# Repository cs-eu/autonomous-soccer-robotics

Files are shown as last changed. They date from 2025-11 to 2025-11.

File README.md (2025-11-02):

# Autonomous Soccer Robot

An autonomous, competition-ready soccer robot designed and built for a educational robotics competition.

---

## Overview

The **Autonomous Soccer Robot** was engineered to:

* Detect and track a ball using 360° vision
* Navigate the field holonomically in any direction
* Handle and shoot the ball autonomously
* Operate completely untethered under RoboCupJunior Soccer rules

Every part — from the **mechanical design** and **custom PCBs** to the **embedded firmware** and **computer vision** algorithms — was developed by our team.

This repository provides a complete, open-source reference for educational and research use.

---

## Project Structure

```
.
├── docs/                # Documentation and reference material
│   ├── electronics/     # Schematics, PCB layouts, and Eagle files
│   ├── hardware/        # CAD designs, drawings, and mechanical notes
│   └── parts-lists/     # Component, ordering, and assembly lists
│
├── firmware/            # Embedded control software (C/C++ / PlatformIO)
│   ├── calibration-tools/  # Sensor calibration and testing utilities
│   ├── main-controller/    # High-level control (movement, PID, logic)
│   ├── sensor-node/        # Sensor acquisition and preprocessing
│   └── tests/              # Unit and integration tests
│
├── libraries/           # Shared hardware abstraction and logic libraries
│   ├── Bodensensoren/   # Floor sensor modules
│   ├── IMU/             # IMU driver and orientation estimation
│   ├── TOF/             # Time-of-Flight distance sensing
│   ├── Motors/          # Motor control and PID regulation
│   ├── TACTICS/         # Robot state machine and strategy modules
│   └── ...              # Additional hardware interface libraries
│
├── mechanical/          # Physical design and fabrication files
│   ├── 3d-models/       # Fusion 360 models and 3D-print files (.stl, .f3d)
│   ├── eagle-pcb/       # Custom PCB layouts and Eagle libraries
│   └── metal-fabrication/ # CNC drawings, step files, and laser-cut designs
│
└── vision/              # Computer vision and image processing
    ├── docker/          # Dockerfiles for OpenCV build environments
    └── tinkerboard/     # Tinker Board vision software (Python + OpenCV)
```

---

## System Architecture

### Hardware Overview

* **Drive System:** Three-wheel omnidirectional base (holonomic drive)
* **Dribbler:** DC-motor-driven adhesive roller for ball handling
* **Kicker:** Solenoid-based shooting mechanism powered via capacitor buffer
* **Main Controller:** Dual **Teensy 3.6** microcontrollers for control & sensing
* **Vision Processor:** **ASUS Tinker Board** running OpenCV (Python)
* **Sensors:**

  * Raspberry Pi camera + parabolic mirror (360° vision)
  * 4× Time-of-Flight (ToF) distance sensors
  * 32× photoresistor array with RGB illumination for boundary detection

---

## Software Overview

| Layer | Platform | Language | Description |
| --- | --- | --- | --- |
| **Vision** | Tinker Board (SBC) | Python + OpenCV | Detects the ball and extracts angular bearing |
| **Control** | Teensy 3.6 | C/C++ (Arduino Framework) | Motion control, PID regulation, actuator management |
| **Communication** | Serial protocol (custom CRC) | C/Python | Reliable low-latency data exchange (<20 ms loop time) |

### Control Loop

The control system computes translational and rotational velocities from sensor inputs, applying:
[
u(t) = K_p e(t) + K_i \int e(t),dt + K_d \frac{de(t)}{dt}
]
Each wheel’s speed is regulated through independent PID loops for smooth, responsive motion.

---

## Mechanical Design

The chassis combines **CNC-milled aluminum** for structural integrity with **3D-printed polymer shells** for lightweight coverage and modular maintenance.
All components were modeled in **Autodesk Fusion 360**, allowing precise alignment and rapid iteration.

---

## Electronics

* **Custom PCBs** for motor drivers, solenoid control, and power regulation
* Designed using **Autodesk Eagle**
* Multiple voltage rails (12V / 5V / 3.3V) with overcurrent and thermal protection
* Modular connectors for fast servicing during competition

---

## Vision and Perception

The 360° vision system uses a **catadioptric setup** (camera + parabolic mirror) to obtain a full panoramic field view.
Processing steps include:

1. Image unwarping to cylindrical projection
2. Color filtering to detect the orange ball
3. Contour and centroid extraction
4. Angular position estimation relative to robot center

Additional data from ToF sensors and photoresistors provide:

* Boundary line detection
* Obstacle proximity sensing
* Position estimation support

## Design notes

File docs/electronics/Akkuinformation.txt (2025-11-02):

Minute  0: 12,6 V
Minute 10: 11,7 V

6x zusätzliches Startup-Warten (Pi zieht 3 A)

danach 725 mAh reingeladen

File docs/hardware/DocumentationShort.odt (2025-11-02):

OborRobotics – Robocup Junior Soccer

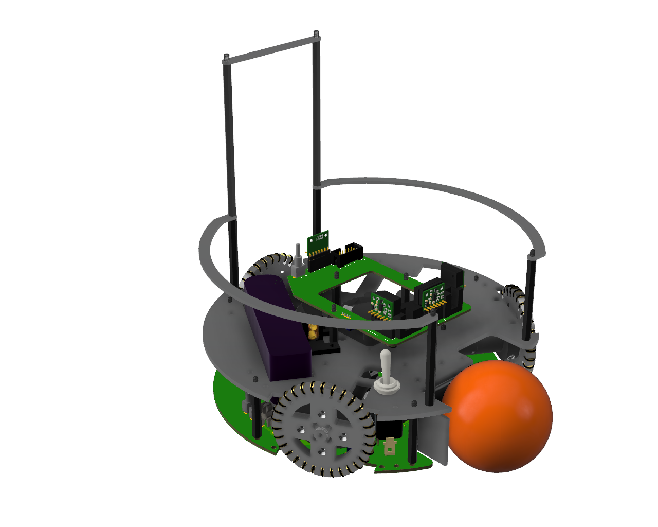
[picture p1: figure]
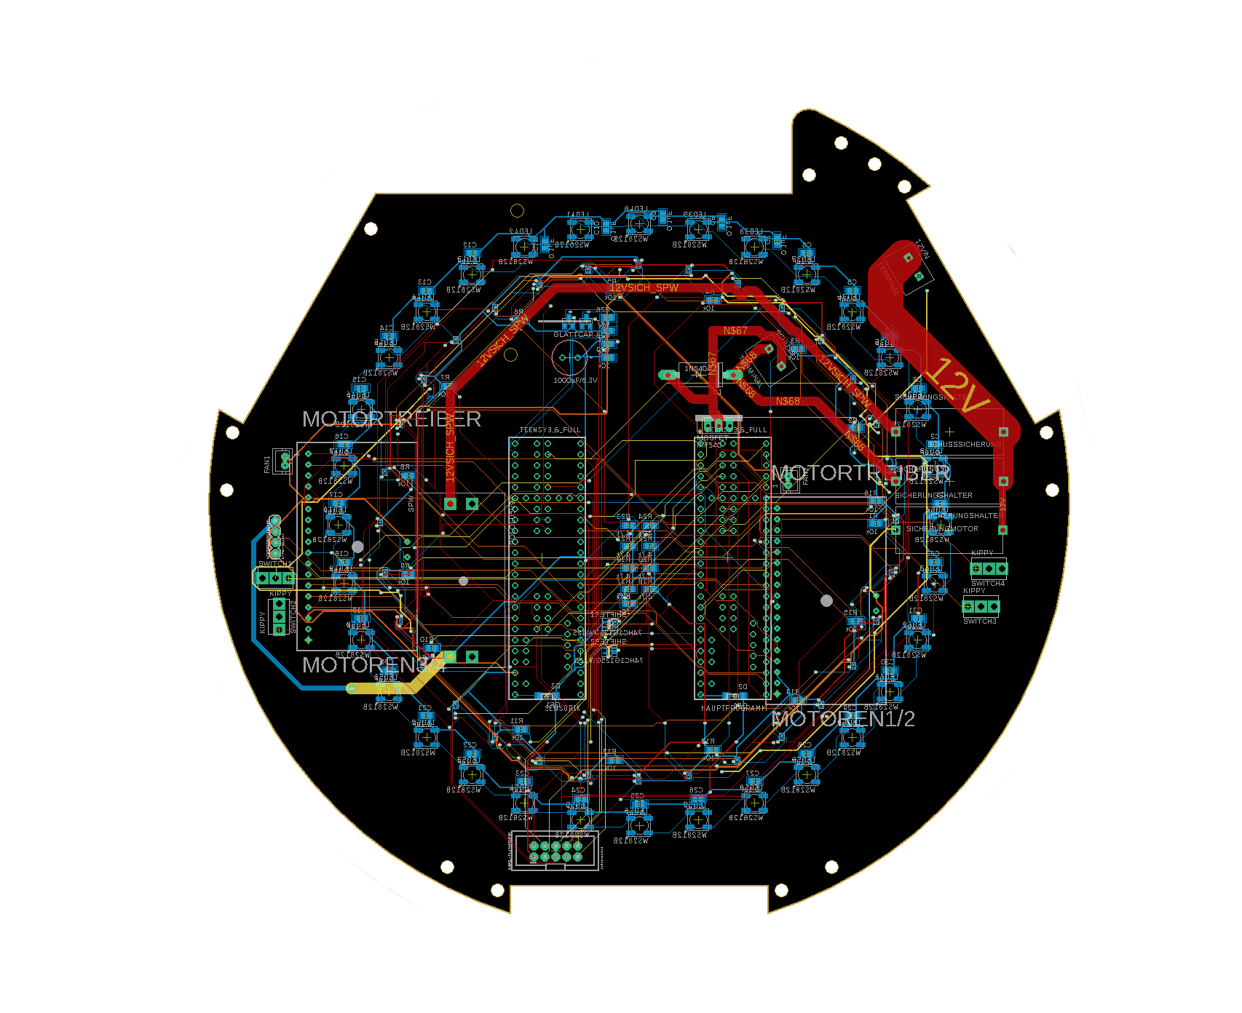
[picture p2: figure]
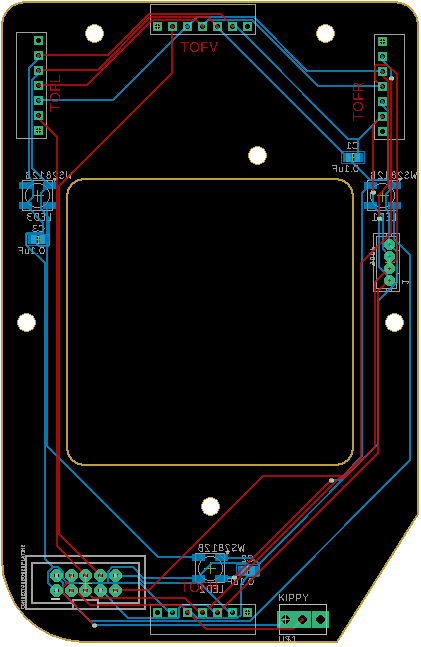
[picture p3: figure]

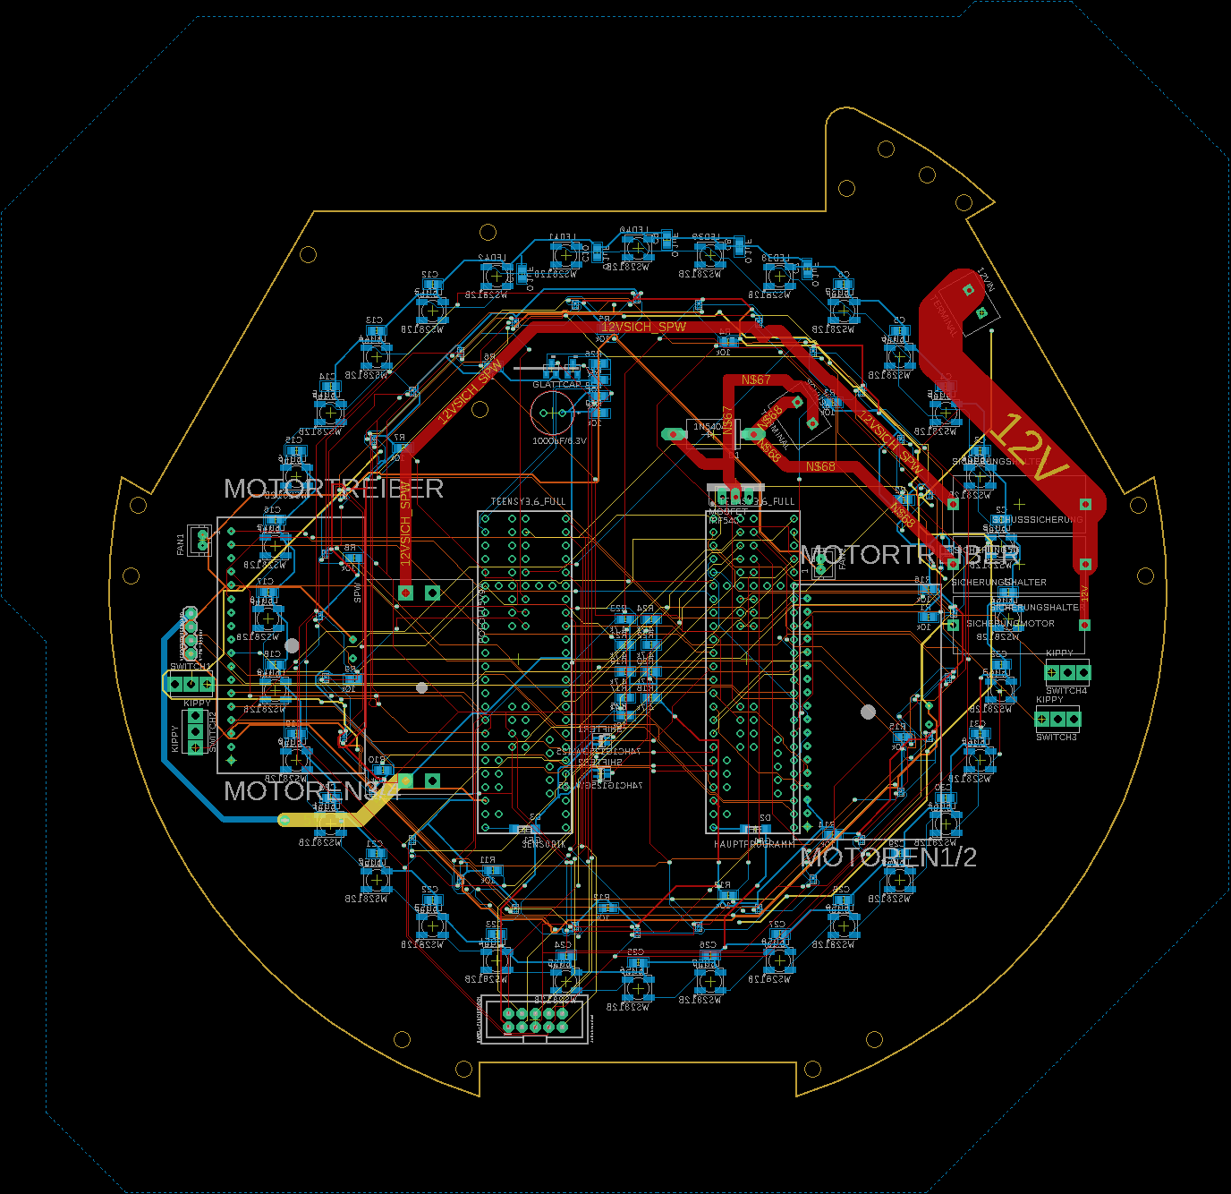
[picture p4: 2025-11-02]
mechanical/3d-models/renders/Pcb1V1.png

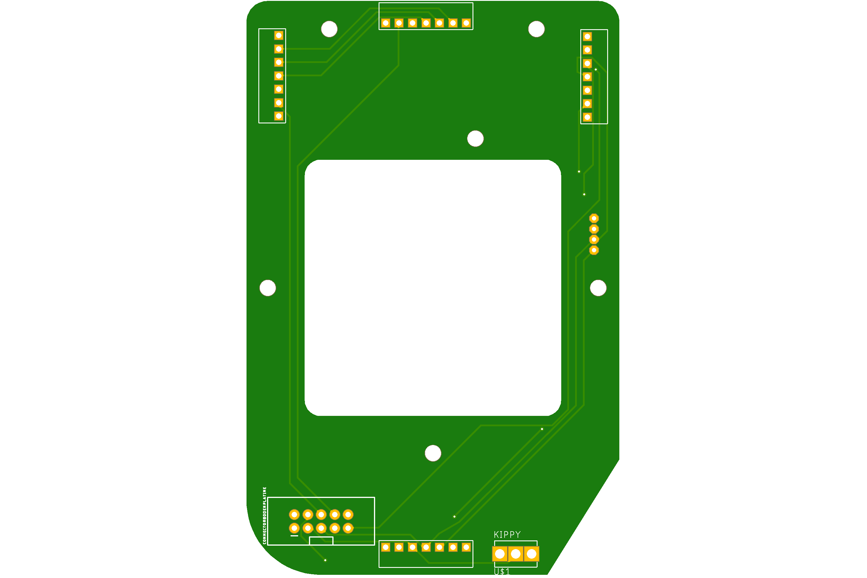
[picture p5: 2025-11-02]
docs/electronics/PlatineObenBoardTop.png

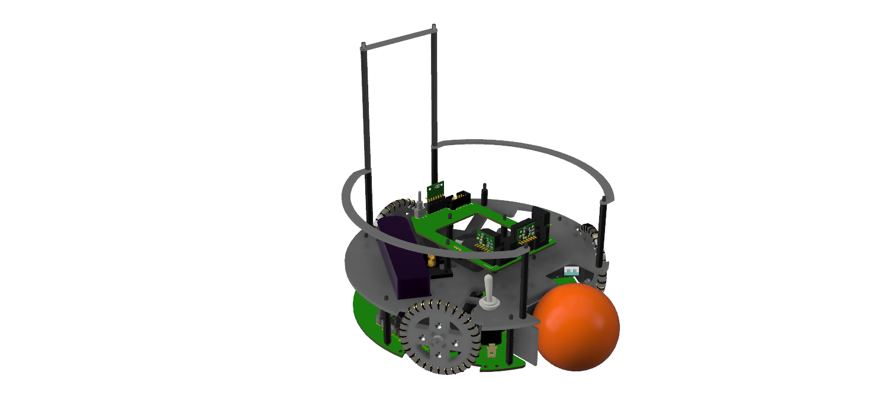
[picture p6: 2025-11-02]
mechanical/3d-models/renders/RenderingRoboV2.png

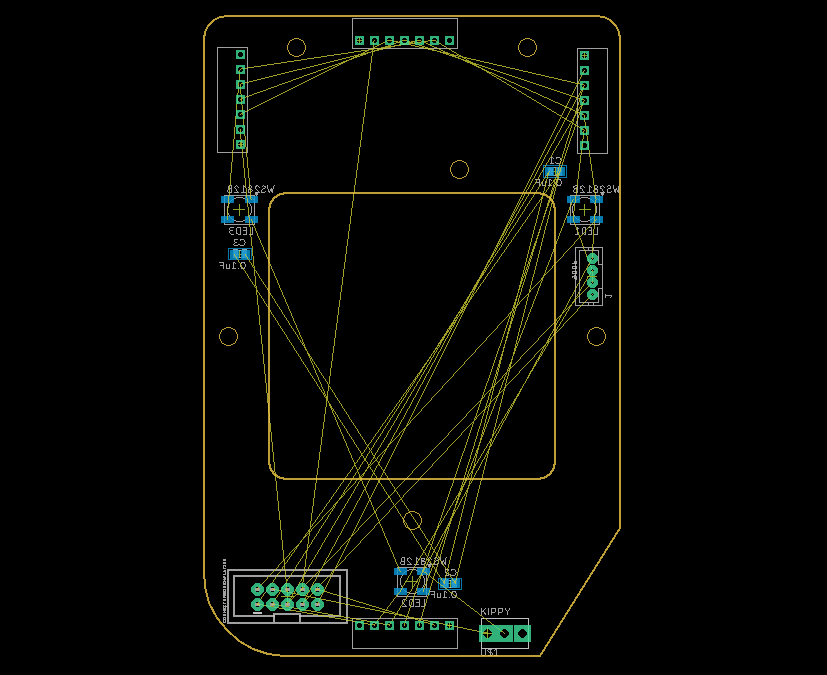
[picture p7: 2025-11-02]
mechanical/3d-models/renders/Pcb2V2.png

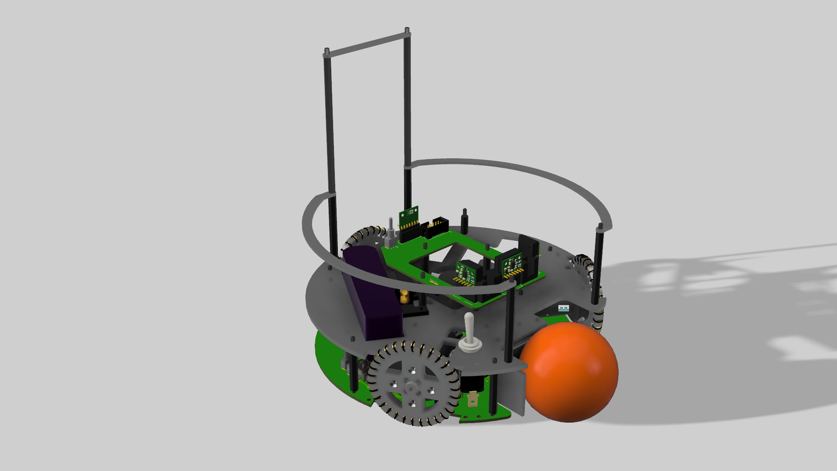
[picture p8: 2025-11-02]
mechanical/3d-models/renders/RenderingRoboV3.png

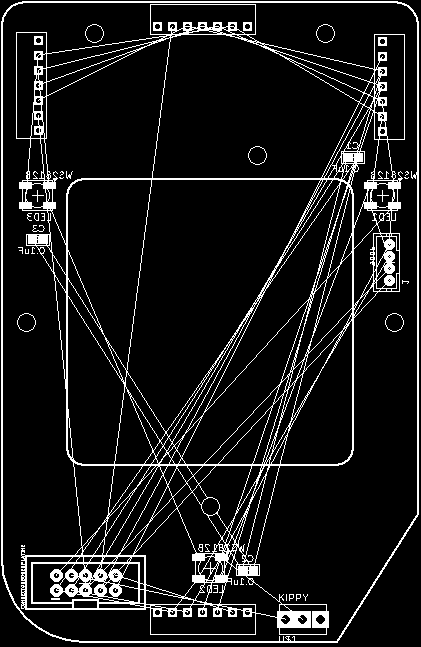
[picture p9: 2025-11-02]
mechanical/3d-models/renders/Pcb2V3.png

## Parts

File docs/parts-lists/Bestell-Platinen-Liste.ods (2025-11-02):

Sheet: Bestellungen_3D-Modelle
 | 3D-Modell benötigt | Step vorhanden?
MotortreiberPins | MotortreiberPlatzhalter | ja
MotortreiberPins | MotortreiberPlatzhalter | ja
Arduino | Anschlussleiste ja, Arduino einzeln | ja
Kompass (Pins)
AkkuPins
UltraschallPins
Fotowiderstände | ja | ja
LEDs | ja | ja
Schalter | ja | ja
StromkreisSchalter | ja | ja
ZustandLEDs | ja | ja
LichtschrankenUltraschall (eventuell)
MotortreiberTermials | ja | ja | https://www.reichelt.de/loetbare-schraubklemme-2-pol-rm-5-mm-90-rnd-205-00012-p170244.html?trstct=pol_0
Pi Zero | ja | ja
Spannungswandler (DEBO DCDC 20W) | ja | ja
Kabel | Platzhalter
Bestellung2:
PiZero x 1
PiCam (RPI JT CAM 5MP) x2
RND 205-00012 :: Lötbare Schraubklemme - 2-pol, RM 5 mm, 90° | reichelt 4x
10x Schalter (https://www.conrad.de/de/kippschalter-125-vac-1-x-einein-tru-components-tc-mk244z-rastend-1-st-1589425.html)
10*Sicherung 1,4 A | https://www.reichelt.de/feinsicherung-5x20mm-mitteltraege-1-4a-mtr-1-4a-p13240.html?&trstct=pol_1
10*Sicherung 10 A | https://www.reichelt.de/feinsicherung-5x20mm-flink-10a-flink-10a-p26479.html?&trstct=pol_0
10*Sicherung 3,15A | https://www.reichelt.de/feinsicherung-5x20mm-flink-3-15a-flink-3-15a-p7836.html?&trstct=pol_0
10*Sicherungshalter 5*20mm | https://www.reichelt.de/sicherungshalter-5x20mm-max-10a-250v-pl-ogn-25-p35196.html?&trstct=pol_4
4*Schuss-Mosfet | https://www.reichelt.de/mosfet-p-ch-100v-23a-140w-to-220ab-irf-9540n-p41638.html?r=1
4*Flyback-Diode | https://www.reichelt.de/gleichrichterdiode-400-v-3-a-do-201ad-1n-5404-p1749.html?r=1
4*Stromkreis-Schalter | https://www.conrad.de/de/sci-kfz-kippschalter-r13-423l-green-12-vdc-30-a-1-x-ausein-rastend-1-st-701050.html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
Kabel + pin header
Schalter:
1x Strom an/aus
1x Programm an/aus
1x Schusstest

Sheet: Pinout
Arduino | Funktion | Eagle? | ZUSATZ | Arduino Nano | Funktion | ZUSATZ
0 |  |  |  | 0 | RX | Arduino Mega
1 |  |  |  | 1 | TX | Arduino Mega
2 | U1E | x |  | 2 | SPI CLOCK
3 | U2E | x |  | 3 | SPI MOSI
4 | U2T | x |  | 4 | SPI MISO
5 | U1T | x |  | 5 | BODEN1
6 | U3T | x |  | 6 | BODEN2
7 | SCHUSS MOSFET | x |  | 7 | BODEN3
8 | U4T | x |  | 8 | BODEN4
9 |  |  |  | 9 | BODEN5
10 | SWITCH1 | x |  | 10 | BODEN6
11 | SWITCH2 | x |  | 11 | BODEN7
12 | SWITCH3 | x |  | 12 | BODEN8
13 | SWITCH4 | x |  | 13
14 | TX |  | RPI | 14
15 | RX |  | RPI | 15
16 | TX | x | Nano (TX Mega) | 16
17 | RX | x | Nano (RX Mega) | 17
18 | U3E | x |  | 18
19 | U4E | x |  | 19
20 | SDA | x | KOMPASS | 20
21 | SCL | x | KOMPASS
22
23
24
25
26
27
28 | M1FB | x | Motor 1 Feedback
29 | M1SF | x | Motor 1 Security
30 | M2FB | x | Motor 2 Feedback
31 | M2SF | x | Motor 2 Security
32 | M3FB | x | Motor 3 Feedback
33 | M3SF | x | Motor 3 Security
34 | M4FB | x | Motor 4 Feedback
35 | M4SF | x | Motor 4 Security
36 | M1D1 | x | Motor 1 Dir 1
37 | M1D2 | x | Motor 1 Dir 2
38 | M2D1 | x | Motor 2 Dir 1
39 | M2D2 | x | Motor 2 Dir 2
40 | M3D1 | x | Motor 3 Dir 1
41 | M3D2 | x | Motor 3 Dir 2
42 | M4D1 | x | Dribbler Dir 1
43 | M4D2 | x | Dribbler Dir 2
44 | M1S | x | PWM
45 | M2S | x | PWM
46 | M3S | x | PWM
47 | M4S | x | NICHT PWM !!!!!! DRIBBLER
48
abxy
14

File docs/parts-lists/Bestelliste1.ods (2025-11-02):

Bezeichnung | Stückzahl | Einzelpreis | Gesamtpreis | Webshop | Artikelnummer | Status | Link
Kugellager Mr105ZZ | 6 | 2,49 € | 14,94 € | Conrad | 295620 – NA | nicht bestellt | https://www.conrad.de/de/p/reely-bb051004-rc-car-kugellager-chromstahl-innen-durchmesser-5-mm-aussen-durchmesser-10-mm-drehzahl-max-50000-u-mi-295620.html
Riemenscheibe Bohrung 3mm | 3 | 3,49 € | 10,47 € | Mechatronics-Pro | 685293887530 | nicht bestellt | https://www.mechatronics-pro.de/de/riemenscheibe-kurz-gt2-6mm-16-zaehne-bohrung-3mm_480.html
Riemenscheibe Bohrung 5mm | 3 | 3,69 € | 11,07 € | Mechatronics-Pro | 685293821480 | nicht bestellt | https://www.mechatronics-pro.de/de/riemenscheibe-kurz-gt2-6mm-20-zaehne-bohrung-5mm_397.html
Lüfter 30x30 | 3 | 10,99 € | 32,97 € | Conrad | 1664489 – NA | nicht bestellt | https://www.conrad.de/de/p/sepa-mfb30e12-axialluefter-12-v-dc-4-0-m-h-l-x-b-x-h-30-x-30-x-6-5-mm-1664489.html
Zahnriemen 96mm | 4 | 2,89 € | 11,56 € | Gtech-Shop | C2-05.05 | nicht bestellt | https://www.gtech-shop.de/GT2-Zahnriemen-6-mm-96-mm-48-Zaehne
Stahlwelle 5mm | 1 | 3,09 € | 3,09 € | Conrad | 237078 - NA | nicht bestellt | https://www.conrad.de/de/p/silberstahl-welle-reely-x-l-5-mm-x-500-mm-237078.html
M4 Sicherungsmutter | 1 | 2,09 € | 2,09 € | Conrad | 223409 - NA | nicht bestellt | https://www.conrad.de/de/p/toolcraft-223409-sicherungsmuttern-m4-din-985-stahl-verzinkt-10-st-223409.html
M4x16 Edelstahl | 10 | 0,14 € | 1,40 € | Conrad | 888747 – NA | nicht bestellt | https://www.conrad.de/de/p/toolcraft-888747-zylinderschrauben-m4-16-mm-innensechskant-din-912-edelstahl-a2-1-st-888747.html
M4 Muttern | 1 | 1,19 € | 1,19 € | Conrad | 888119 – NA | nicht bestellt | https://www.conrad.de/de/p/toolcraft-888119-sechskantmuttern-m4-din-934-edelstahl-a2-10-st-888119.html
M3x10 Edelstahl | 25 | 0,07 € | 1,75 € | Conrad | 888738 – NA | nicht bestellt | https://www.conrad.de/de/p/toolcraft-888738-zylinderschrauben-m3-10-mm-innensechskant-din-912-edelstahl-a2-1-st-888738.html
M3x12 Edelstahl | 30 | 0,08 € | 2,40 € | Conrad | 888739 – NA | nicht bestellt | https://www.conrad.de/de/p/toolcraft-888739-zylinderschrauben-m3-12-mm-innensechskant-din-912-edelstahl-a2-1-st-888739.html
M4x12 Senkkopf | 10 | 0,10 € | 1,00 € | Conrad | 889768 – NA | nicht bestellt | https://www.conrad.de/de/p/toolcraft-889768-senkschrauben-m4-12-mm-kreuzschlitz-phillips-din-965-stahl-verzinkt-1-st-889768.html
M4x4 Gewindestift | 1 | 1,49 € | 1,49 € | Conrad | 1789865 – NA | nicht bestellt | https://www.conrad.de/de/p/toolcraft-to-5369595-gewindestift-m4-4-mm-edelstahl-a1-a2-50-st-1789865.html
M3x10 Senkkopf | 1 | 3,49 € | 3,49 € | Conrad | 1791990 – NA | nicht bestellt | https://www.conrad.de/de/p/toolcraft-to-5375970-senkschrauben-m3-10-mm-kreuzschlitz-phillips-iso-7046-edelstahl-a2-200-st-1791990.html
M2x8 Edelstahl | 15 | 0,31 € | 4,65 € | Conrad | 888725 – NA | nicht bestellt | https://www.conrad.de/de/p/toolcraft-888725-zylinderschrauben-m2-8-mm-innensechskant-din-912-edelstahl-a2-1-st-888725.html
M2x6 Senkkopf | 10 | 0,08 € | 0,80 € | Conrad | 889751 – NA | nicht bestellt | https://www.conrad.de/de/p/toolcraft-889751-senkschrauben-m2-6-mm-kreuzschlitz-phillips-din-965-stahl-verzinkt-1-st-889751.html
M2.5x16 Senkkopf | 1 | 3,99 € | 3,99 € | Conrad | 1810566 – NA | nicht bestellt | https://www.conrad.de/de/p/toolcraft-to-5431698-senkschrauben-m2-5-16-mm-kreuzschlitz-phillips-iso-7046-stahl-galvanisch-verzinkt-200-st-1810566.html
M2.5 Muttern | 1 | 1,29 € | 1,29 € | Conrad | 106856 – NA | nicht bestellt | https://www.conrad.de/de/p/toolcraft-106856-sechskantmuttern-m2-5-din-439-stahl-100-st-106856.html
Encoder | 9 | 14,74 € | 132,66 € | Mouser | 985-AS5601-SO_EK_A | nicht bestellt | https://www.mouser.de/ProductDetail/ams/AS5601-SO_EK_AB?qs=pqSajtDZXRWFkB8SVj5xrw%3D%3D
Abstandsbolzen 40mm M3 | 1 | 3,49 € | 3,49 € | Conrad | 521716 – NA | nicht bestellt | https://www.conrad.de/de/p/pb-fastener-s45530x40-abstandsbolzen-l-40-mm-m3-x-7-m3-x-6-stahl-verzinkt-10-st-521716.html
M3x12 Senkkopf | 25 | 0,07 € | 1,75 € | Conrad | 889762 – NA | nicht bestellt | https://www.conrad.de/de/p/toolcraft-889762-senkschrauben-m3-12-mm-kreuzschlitz-phillips-din-965-stahl-verzinkt-1-st-889762.html
Abstandsbolzen 20mm M3 | 20 | 0,30 € | 6,00 € | Conrad | 526657 – 62 | nicht bestellt | https://www.conrad.de/de/p/6035-20-m3-abstandsbolzen-l-20-mm-m3-m3-messing-1-st-526657.html
M3x8 Edelstahl | 25 | 0,09 € | 2,25 € | Conrad | 888736 – 62 | nicht bestellt | https://www.conrad.de/de/p/toolcraft-888736-zylinderschrauben-m3-8-mm-innensechskant-din-912-edelstahl-a2-1-st-888736.html
M3 Muttern | 1 | 0,82 € | 0,82 € | Conrad | 131880 – 62 | nicht bestellt | https://www.conrad.de/de/p/toolcraft-131880-sechskantmuttern-m3-din-934-stahl-100-st-131880.html
M3x20 Senkkopf | 10 | 0,08 € | 0,80 € | Conrad | 889764 – 62 | nicht bestellt | https://www.conrad.de/de/p/toolcraft-889764-senkschrauben-m3-20-mm-kreuzschlitz-phillips-din-965-stahl-verzinkt-1-st-889764.html
Platine: |  |  |  |  |  | nicht bestellt
Teensy 4.0 | 3 | 29,50 € | 88,50 € | Reichelt | TEENSY 4.0 | nicht bestellt | https://www.reichelt.de/teensy-4-0-usb-teensy-4-0-p269006.html?&trstct=pos_0&nbc=1
Stiftleiste 1*14 | 6 | 0,69 € | 4,14 € | Reichelt | BKL 10120917 | nicht bestellt | https://www.reichelt.de/stiftleiste-2-54mm-1x14-h-11-6mm-gerade-bkl-10120917-p262781.html?trstct=pol_25&nbc=1
Buchsenleiste 1*14 | 6 |  | 0,00 € |  |  | nicht bestellt
Stiftleiste 2*5 | 3 |  | 0,00 € |  |  | nicht bestellt
Buchsenleiste 2*5 | 3 |  | 0,00 € |  |  | nicht bestellt
Stiftleiste 1*5 | 3 | 0,29 € | 0,87 € | Reichelt | BKL 10120502 | nicht bestellt | https://www.reichelt.de/stiftleiste-5-polig-vergoldet-2-54mm-bkl-10120502-p235653.html?trstct=pol_4&nbc=1
Buchsenleiste 1*5 | 3 |  | 0,00 € |  |  | nicht bestellt
Teensy 3.6 | 0 | 0,00 € | 0,00 € |  |  | nicht bestellt
Buchsenleiste 1*24 | 6 |  | 0,00 € |  |  | nicht bestellt
Buchsenleiste 2*3 | 3 |  | 0,00 € |  |  | nicht bestellt
Buchsenleiste 2*4 | 3 |  | 0,00 € |  |  | nicht bestellt
Buchsenleiste 2*5 | 3 |  | 0,00 € |  |  | nicht bestellt
Led WS2812B | 96 |  | 0,00 € |  |  | nicht bestellt
Levelshifter | 6 |  | 0,00 € |  |  | nicht bestellt
Kondensatoren 1u.F | 96 |  | 0,00 € |  |  | nicht bestellt
I2C Multiplexer TCA9548APWR | 12 | 1,15 € | 13,80 € | Mouser | 595-TCA9548APWR | nicht bestellt | https://www.mouser.de/ProductDetail/Texas-Instruments/TCA9548APWR?qs=sGAEpiMZZMsKdvST4JBTTEPriY5kCzuu
Widerstand 4.7kO | 216 |  | 0,00 € |  |  | nicht bestellt
Widerstand 10kO | 12 |  | 0,00 € |  |  | nicht bestellt
BodensensorenTSL2584TSV | 96 |  | 0,00 € |  |  | nicht bestellt
Motorcontroller DRV8320HRTV | 12 | 2,59 € | 31,08 € | Mouser |  | nicht bestellt
Mosfets TPH9R506PL | 72 | 0,66 € | 47,30 € | Mouser | 757-TPH9R506PLLQ | nicht bestellt | https://www.mouser.de/ProductDetail/Toshiba/TPH9R506PLLQ
Motorconnector TE1-84953-1 | 12 | 0,94 € | 11,28 € | Mouser | 571-1-84953-1 | nicht bestellt | https://www.mouser.de/ProductDetail/TE-Connectivity/1-84953-1/?qs=uUkeXfjQ8uQbyHjuXR99Yw%3D%3D

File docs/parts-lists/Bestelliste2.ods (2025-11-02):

Bauteil | Kosten | Anzahl | Webshop | Artikelnummer | Status | Link
PiCam (RPI JT CAM 5MP) | 15,95 € | 2 | Reichelt | RPI JT CAM 5MP | geliefert | https://www.reichelt.de/raspberry-pi-kamera-5mp-inkl-stromversorgung-rpi-jt-cam-5mp-p218887.html?trstct=pos_0
Lötbare Schraubklemme | 0,21 € | 12 | Reichelt | RND 205-00012 | geliefert | https://www.reichelt.de/loetbare-schraubklemme-2-pol-rm-5-mm-90-rnd-205-00012-p170244.html?trstct=pos_0
Sicherung 1,4 A | 0,42 € | 10 | Reichelt | MTR. 1,4A | geliefert | https://www.reichelt.de/feinsicherung-5x20mm-mitteltraege-1-4a-mtr-1-4a-p13240.html?&trstct=pol_1
Sicherung 10 A | 0,32 € | 10 | Reichelt | FLINK 10A | geliefert | https://www.reichelt.de/feinsicherung-5x20mm-flink-10a-flink-10a-p26479.html?&trstct=pol_0
Sicherung 3,15A | 0,30 € | 10 | Reichelt | FLINK 3,15A | geliefert | https://www.reichelt.de/feinsicherung-5x20mm-flink-3-15a-flink-3-15a-p7836.html?&trstct=pol_0
Sicherungshalter 5*20mm | 0,45 € | 10 | Reichelt | PL OGN-25 | geliefert | https://www.reichelt.de/sicherungshalter-5x20mm-max-10a-250v-pl-ogn-25-p35196.html?&trstct=pol_4
Schuss-Mosfet | 0,67 € | 8 | Reichelt | IRF 9540N | geliefert | https://www.reichelt.de/mosfet-p-ch-100v-23a-140w-to-220abtirf-9540n-p41638.html?r=1
Flyback-Diode | 0,06 € | 8 | Reichelt | 1N 5404 | geliefert | https://www.reichelt.de/gleichrichterdiode-400-v-3-a-do-201ad-1n-5404-p1749.html?r=1
Arduino Stiftleiste 2-reihig 36-polig | 0,17 € | 4 | Reichelt | SL 1X36G 2,54 | geliefert | https://www.reichelt.de/36pol-stiftleiste-gerade-rm-2-54-sl-1x36g-2-54-p19504.html?trstct=lsbght_sldr::51696
Arduino Stiftleiste 1-reihig 36-polig | 0,23 € | 3 | Reichelt | SL 2X36G 2,54 | geliefert | https://www.reichelt.de/2x36pol-stiftleiste-gerade-rm-2-54-sl-2x36g-2-54-p19496.html?&trstct=pol_5
Pin-Header für Kompass-Kabel | 1,25 € | 3 | Reichelt | GRV CONNEC4PIN | geliefert | https://www.reichelt.de/arduino-grove-universal-buchse-4-pin-10er-pack-grv-connec4pin-p191135.html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
Kabel für RasPi | 2,95 € | 3 | Reichelt | DELOCK 85360 | geliefert | https://www.reichelt.de/delock-kabel-power-4-pin-stecker-4-pin-buchse-pwm-10-cm-delock-85360-p220121.html
Lange Pins für Jumper an Motortreiber | 0,87 € | 2 | Reichelt | STAPELLEISTE 20 | geliefert | https://www.reichelt.de/stapelleiste-20-polig-einreihig-hoehe-38mm-stapelleiste-20-p19453.html?trstct=vrt_pdn
Schalter | 1,80 € | 5 | Conrad | 1589425 – 62 | geliefert | https://www.conrad.de/de/kippschalter-125-vac-1-x-einein-tru-components-tc-mk244z-rastend-1-st-1589425.html
Kugellager-Lagerblock | 6,79 € | 6 | Conrad | 216011 - 62 | geliefert | https://www.conrad.de/de/lagerbock-reely-16-bohrungs-o-16-mm-216011.html?sc.ref=Product%20Details
Kugellager Innendurchmesser 4mm | 2,79 € | 6 | Conrad | 221925 - 62 | geliefert | https://www.conrad.de/de/reely-kugellager-radial-chromstahl-innen-durchmesser-4-mm-aussen-durchmesser-16-mm-drehzahl-max-41000-umin-221925.html
Stromkreis-Schalter | 4,69 € | 6 | Conrad | 701050 – 62 | geliefert | https://www.conrad.de/de/sci-kfz-kippschalter-r13-423l-green-12-vdc-30-a-1-x-ausein-rastend-1-st-701050.html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
Steck-Verbinder für Arduino-Platinen-Kabel | 0,59 € | 5 | Farnell | 2215314 | geliefert | https://de.farnell.com/amphenol/t821140a1s100ceu/stiftleiste-vertikal-2-54mm-40pol/dp/2215314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
Arduino-Platinen-Kabel | 4,18 € | 4 | Farnell | 2217617 | geliefert | https://de.farnell.com/amphenol/fc40150-0/kabel-2-54mm-f-f-150mm-40pol/dp/2217617
Rollenkette Teilung 5mm |  | 30cm | Ketten Fuchs | ER 005 | geliefert | https://www.kettenfuchs.de/index.php?id=60#c1365
Rollenketten-Verschlussglied Teilung 5mm |  | 3 | Ketten Fuchs | 1E-ER-005 | geliefert | https://www.kettenfuchs.de/index.php?id=60#c1365
Kettenrad Teilung 5mm |  | 6 | Ketten Fuchs | 321-005-008 | geliefert | https://www.kettenfuchs.de/index.php?id=148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
Motorshields | 28,51 € | 5 | Eckstein Komponente | PO1213 | geliefert | https://eckstein-shop.de/Pololu-Dual-MC33926-Motor-Driver-Carrier
Arduino nano | 7,95 € | 3 | Eckstein Komponente | AR01003 | geliefert | https://eckstein-shop.de/HIMALAYA-basic-Nano-Board-ATMEGA-mit-mini-USB-Kabel-Arduino-kompatibel-FTDI-FT232RL-USB-UART-IC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
Benötigt für:
Test der Gesamtschaltung
Verwendung auf endgültiger Platine
Dribbler

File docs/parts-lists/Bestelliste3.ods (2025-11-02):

Bauteil | Kosten | Anzahl | Webshop | Artikelnummer | Status | Link
Buchsenleiste | 0,72 € | 5 | Reichelt | BL 1X20G 2,54 | tu es | https://www.reichelt.de/20pol-buchsenleiste-gerade-rm-2-54-bl-1x20g-2-54-p6072.html
Plexiglasröhre | 27,00 € | 1m | Plattenzuschnitt24 | C60000-RO3-080 | tu es | https://www.plattenzuschnitt24.de/Plexiglas-XT-Rohr-3mm-farblos-80-74.html
Kardangelenk | 4,50 € | 5 | Voelkner | S132821 | tu es | https://www.voelkner.de/products/978431/Thicon-Models-20036-Kardangelenk-Stahl-3-17-4mm-23mm-lang-1St..html

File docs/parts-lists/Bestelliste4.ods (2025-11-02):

Artikel | Stückzahl | Einzelpreis | Gesamtpreis | Webshop | Artikelnummer | Status | Link
Micro USB Kabel Links gewinkelt | 2 | 4,69 € | 9,38 € | Amazon | CY Micro-USB-Host OTG-Kabel für Galaxy S4 i9500 N7100 i9220 i9100 XOOM, links abgewinkelt | nicht bestellt | https://www.amazon.de/Micro-USB-Host-OTG-Kabel-Galaxy-i9500-abgewinkelt/dp/B00S6IQD9U
Micro USB Kabel Rechts gewinkelt | 2 | 3,80 € | 7,60 € | Amazon | Delock Kabel Micro USB Typ-B Stecker gewinkelt > USB 2.0-A Buchse OTG 11 cm | nicht bestellt | https://www.amazon.de/Delock-Kabel-Stecker-gewinkelt-Buchse/dp/B006TCXLF4
Abstandsbolzen M3 100mm Stahl | 10 | 1,42 € | 14,16 € | Buerklin | 18 H 200 | nicht bestellt | https://www.buerklin.com/de/abstandsbolzen-aussen-innen--m3-m3-100mm/p/18h200
Abstandsbolzen M3 55mm Stahl | 10 | 0,61 € | 6,07 € | Buerklin | 18 H 192 | nicht bestellt | https://www.buerklin.com/de/abstandsbolzen-aussen-innen--m3-m3-55mm/p/18h192
Abstandsbolzen M3 35mm Stahl | 20 | 0,30 € | 6,02 € | Buerklin | 18 H 184 | nicht bestellt | https://www.buerklin.com/de/abstandsbolzen-aussen-innen--m3-m3-35mm/p/18h184
Abstandsbolzen M3 15mm Plastik | 10 | 0,23 € | 2,34 € | Buerklin | 18 H 3685 | nicht bestellt | https://www.buerklin.com/de/abstandsbolzen-aussen-innen--m3-m3-15mm/p/18h3685
Abstandsbolzen M3 20mm Plastik | 10 | 0,43 € | 4,25 € | Buerklin | 18 H 3687 | nicht bestellt | https://www.buerklin.com/de/abstandsbolzen-aussen-innen--m3-m3-20mm/p/18h3687
Abstandsbolzen M3 30mm Stahl | 10 | 0,41 € | 4,08 € | Buerklin | 18 H 182 | nicht bestellt | https://www.buerklin.com/de/abstandsbolzen-aussen-innen--m3-m3-30mm/p/18h182
Abstandsbolzen M2 8mm Messing | 10 | 0,14 € | 1,38 € | Buerklin | 18 H 2402 | nicht bestellt | https://www.buerklin.com/de/abstandsbolzen-innen-innen--m2-m2-8mm/p/18h2402
Spannungswandler 5V 9A | 3 | 25,30 € | 75,90 € | ExpTech | EXP-R25-376 | nicht bestellt | https://www.exp-tech.de/module/stromspannung/6005/pololu-5v-9a-step-down-voltage-regulator-d24v90f5
Time of Flight Sensor | 8 | 11,38 € | 91,04 € | ExpTech | EXP-R25-1092 | nicht bestellt | https://www.exp-tech.de/en/sensors/distanceapproximation/8756/pololu-vl53l1x-time-of-flight-distance-sensor-carrier-with-voltage-regulator-400cm-max
Kompass Kabel 5cm | 1 | 1,79 € | 1,79 € | ExpTech | EXP-R02-562 | nicht bestellt | https://www.exp-tech.de/zubehoer/kabel/grove/7943/seeed-studio-grove-universal-4-pin-buckled-5cm-cable-5-pcs-pack
Neopixel 5050 WS2812B – 10 Pack | 11 | 2,38 € | 26,18 € | ExpTech | EXP-R15-315 | nicht bestellt | https://www.exp-tech.de/zubehoer/led-leuchtmittel/5598/neopixel-5050-rgb-led-with-integrated-driver-chip-10-pack
Wärmeleitfolie | 1 | 4,95 € | 4,95 € | ExpTech | EXP-R15-1053 | nicht bestellt | https://www.exp-tech.de/zubehoer/sonstige/7387/heat-sink-thermal-tape-3m-8810-80mm-x-80mm
Bodensensoren | 100 | 1,08 € | 108,00 € | Mouser | TSL2584TSV | Habemus | https://www.mouser.de/ProductDetail/985-TSL2584
Kondensator 0,1uF | 110 | 0,04 € | 4,29 € | Mouser | 710-885012207072 | Habemus | https://www.mouser.de/ProductDetail/Wurth-Electronics/885012207072
5V-Glättungskondensator | 5 | 0,98 € | 4,90 € | Mouser | 710-870135174006 | nicht bestellt | https://www.mouser.de/ProductDetail/Wurth-Electronics/870135174006
NeoPixel-Signal-Wandler | 10 | 0,23 € | 2,28 € | Mouser | 771-74HC1G125GW-G | Habemus | https://www.mouser.de/ProductDetail/Nexperia/74HC1G125GW125?qs=P62ublwmbi98oS26kHEtTw%3D%3D
I2C-Signal-Wandler-MOSFETs | 10 | 0,24 € | 2,43 € | Mouser | 512-BSS138 | nicht bestellt | https://www.mouser.de/ProductDetail/ON-Semiconductor-Fairchild/BSS138?qs=sGAEpiMZZMvlOED0T0kTWl5MKyjMqq%2Fg
Plexiglasrohr 11cm | 2 | 8,64 € | 17,28 € | Plattenzuschnitt24 | C60000-RO3-080 | nicht bestellt | https://www.plattenzuschnitt24.de/Plexiglas-XT-Rohr-3mm-farblos-80-74.html
Teensy 3.6 | 4 | 38,90 € | 155,60 € | Reichelt | TEENSY 3.6 | geliefert | https://www.reichelt.de/teensy-3-6-usb-teensy-3-6-p191458.html?&trstct=pos_0
Fan Connector | 6 | 0,30 € | 1,80 € | Reichelt | PS 25/2G BR | geliefert | https://www.reichelt.de/platinensteckverbinder-gerade-braun-2-polig-ps-25-2g-br-p38232.html
Siftleiste | 4 | 0,37 € | 1,48 € | Reichelt | SL 1X50G 2,54 | nicht bestellt | https://www.reichelt.de/50pol-stiftleiste-gerade-rm-2-54-sl-1x50g-2-54-p19508.html?&trstct=pol_0
SMD Stiftleiste | 1 | 0,48 € | 0,48 € | Reichelt | SL 2X10G SMD2,54 | nicht bestellt | https://www.reichelt.de/2x10pol-smd-stiftleiste-gerade-rm-2-54-sl-2x10g-smd2-54-p51717.html?trstct=pol_0
SMD Stiftleiste | 1 | 1,70 € | 1,70 € | Reichelt | SL 2X40G SMD2,54 | nicht bestellt | https://www.reichelt.de/2x40pol-smd-stiftleiste-gerade-rm-2-54-sl-2x40g-smd2-54-p51725.html?trstct=pol_2
Buchsenleiste | 8 | 0,27 € | 2,16 € | Reichelt | BL 1X20G8 2,54 | nicht bestellt | https://www.reichelt.de/20pol-buchsenleiste-gerade-rm-2-54-h-8-5mm-bl-1x20g8-2-54-p51827.html?trstct=pol_0
Buchsenleiste | 8 | 0,16 € | 1,28 € | Reichelt | MPE 094-1-004 | geliefert | https://www.reichelt.de/buchsenleisten-2-54-mm-1x04-gerade-mpe-094-1-004-p119913.html?&trstct=pol_1
Buchsenleiste | 4 | 0,21 € | 0,84 € | Reichelt | RND 205-00654 | geliefert | https://www.reichelt.de/rnd-buchsenleiste-10-pol-rm-2-54-mm-rnd-205-00654-p208880.html?&trstct=pol_0
Buchsenleiste | 4 | 0,18 € | 0,72 € | Reichelt | RND 205-00653 | nicht bestellt | https://www.reichelt.de/rnd-buchsenleiste-8-pol-rm-2-54-mm-rnd-205-00653-p208879.html?&trstct=pol_0
Buchsenleiste | 4 | 0,15 € | 0,60 € | Reichelt | RND 205-00652 | geliefert | https://www.reichelt.de/rnd-buchsenleiste-6-pol-rm-2-54-mm-rnd-205-00652-p208878.html?&trstct=pol_0
Buchsenleiste | 4 | 0,11 € | 0,44 € | Reichelt | RND 205-00645 | nicht bestellt | https://www.reichelt.de/rnd-buchsenleiste-5-pol-rm-2-54-mm-rnd-205-00645-p208871.html?&trstct=pol_0
Buchsenleiste | 8 | 0,14 € | 1,12 € | Reichelt | RND 205-00647 | geliefert | https://www.reichelt.de/rnd-buchsenleiste-7-pol-rm-2-54-mm-rnd-205-00647-p208873.html?&trstct=pol_0
Fan | 4 | 1,65 € | 6,60 € | Reichelt | FAN-4010 12V | nicht bestellt | https://www.reichelt.de/fan-12-v-dc-40-x-40-x-10-mm-rpm-5800-fan-4010-12v-p11004.html?r=1
Flachbandkabel | 1 | 2,90 € | 2,90 € | Reichelt | AWG 28-10G 3M | geliefert | https://www.reichelt.de/flachbandkabel-awg28-10-pol-grau-3m-ring-awg-28-10g-3m-p47637.html?trstct=pos_0
Flachband Buchse | 4 | 0,10 € | 0,40 € | Reichelt | PFL 10 | nicht bestellt | https://www.reichelt.de/pfostenbuchse-10-polig-mit-zugentlastung-pfl-10-p14571.html?&trstct=pos_0
Flachband Stecker | 6 | 0,10 € | 0,60 € | Reichelt | WSL 10G | nicht bestellt | https://www.reichelt.de/wannenstecker-10-polig-gerade-wsl-10g-p22816.html?&trstct=pos_0
SMD Diode | 6 | 0,14 € | 0,84 € | Reichelt | DO-214AC/SMA | nicht bestellt | https://www.reichelt.de/gleichrichterdiode-100-v-2-a-do-214ac-sma-es-2ba-smd-p95406.html?trstct=pol_15
Kühlkörper (2x pro Chip) | 32 | 0,38 € | 12,16 € | Reichelt | ICK SMD A 13 SA | geliefert13 | https://www.reichelt.de/kuehlkoerper-smd-13-mm-alu-63-k-w-ick-smd-a-13-sa-p227833.html?&trstct=pol_7
Stiftleiste Spannungswandler | 1 | 1,10 € | 1,10 € | Reichelt | RND 205-00554 | nicht bestellt | https://www.reichelt.de/stiftleiste-24-pol-gerade-rm-5-08-rnd-205-00554-p253027.html?trstct=pol_0&r=1
2,4mm Megapixel Lens | 1 | 17,80 € | 17,80 € | VisionDimension | 302101 | nicht bestellt | https://www.vision-dimension.com/de/objektive/mini-objektive/megapixel-miniobjektive/2-4mm-fisheye-1320-oeffnungswinkel-megapixel-board-lens-ir-format-1/3-s-m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
10k Widerstände | 63 | 0,05 € | 3,21 € | Mouser | CRCW080510K0FKEAC | Habemus | https://www.mouser.de/ProductDetail/Vishay/CRCW080510K0FKEAC?qs=sGAEpiMZZMtlubZbdhIBIIZe04wfiaJWcT48uZO055s%3D
4.7k Widerstände | 24 | 0,02 € | 0,58 € | Mouser | 71-CRCW08054K70FKEBC | Habemus | https://www.mouser.de/ProductDetail/Vishay/CRCW08054K70FKEBC
 |  | Gesamt: | 608,73 €
 |  |  |  |  |  | bestellt
 |  |  |  |  |  | geliefert

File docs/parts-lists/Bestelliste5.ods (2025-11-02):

Artikel | Stückzahl | Einzelpreis | Gesamtpreis | Webshop | Artikelnummer | Status | Link
Abstandsbolzen M3 100mm Stahl | 10 | 1,42 € | 14,16 € | Buerklin | 18 H 200 | geliefert | https://www.buerklin.com/de/Produkte/Elektromechanik/Befestigungsmaterial-und-Montagematerial/Abstandsbolzen/Sechskantabstandbolzen/Abstandsbolzen%2C-Au%C3%9F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
Abstandsbolzen M3 55mm Stahl | 10 | 0,61 € | 6,07 € | Buerklin | 18 H 192 | geliefert | https://www.buerklin.com/de/Produkte/Elektromechanik/Befestigungsmaterial-und-Montagematerial/Abstandsbolzen/Sechskantabstandbolzen/Abstandsbolzen%2C-Au%C3%9F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
Abstandsbolzen M3 35mm Stahl | 20 | 0,30 € | 6,02 € | Buerklin | 18 H 184 | geliefert | https://www.buerklin.com/de/Produkte/Elektromechanik/Befestigungsmaterial-und-Montagematerial/Abstandsbolzen/Sechskantabstandbolzen/Abstandsbolzen%2C-Au%C3%9F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
Abstandsbolzen M3 15mm Plastik | 10 | 0,23 € | 2,34 € | Buerklin | 18 H 3685 | geliefert | https://www.buerklin.com/de/Produkte/Elektromechanik/Befestigungsmaterial-und-Montagematerial/Abstandsbolzen/Sechskantabstandbolzen/Abstandsbolzen%2C-Au%C3%9F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
Abstandsbolzen M3 20mm Plastik | 10 | 0,43 € | 4,25 € | Buerklin | 18 H 3687 | geliefert | https://www.buerklin.com/de/abstandsbolzen-aussen-innen--m3-m3-20mm/p/18h3687
Abstandsbolzen M3 30mm Stahl | 10 | 0,41 € | 4,08 € | Buerklin | 18 H 182 | geliefert | https://www.buerklin.com/de/Produkte/Elektromechanik/Befestigungsmaterial-und-Montagematerial/Abstandsbolzen/Sechskantabstandbolzen/Abstandsbolzen%2C-Au%C3%9F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
Abstandsbolzen M2 8mm Messing | 10 | 0,14 € | 1,38 € | Buerklin | 18 H 2402 | geliefert | https://www.buerklin.com/de/abstandsbolzen-innen-innen--m2-m2-8mm/p/18h2402
Spannungswandler 5V 9A | 3 | 25,30 € | 75,90 € | ExpTech | EXP-R25-376 | geliefert | https://www.exp-tech.de/module/stromspannung/6005/pololu-5v-9a-step-down-voltage-regulator-d24v90f5
Time of Flight Sensor | 8 | 11,38 € | 91,04 € | ExpTech | EXP-R25-1092 | geliefert | https://www.exp-tech.de/en/sensors/distanceapproximation/8756/pololu-vl53l1x-time-of-flight-distance-sensor-carrier-with-voltage-regulator-400cm-max
Kompass Kabel 5cm | 1 | 1,79 € | 1,79 € | ExpTech | EXP-R02-562 | geliefert | https://www.exp-tech.de/zubehoer/kabel/grove/7943/seeed-studio-grove-universal-4-pin-buckled-5cm-cable-5-pcs-pack
Neopixel 5050 WS2812B – 10 Pack | 11 | 2,38 € | 26,18 € | ExpTech | EXP-R15-315 | geliefert | https://www.exp-tech.de/zubehoer/led-leuchtmittel/5598/neopixel-5050-rgb-led-with-integrated-driver-chip-10-pack
Wärmeleitfolie | 1 | 4,95 € | 4,95 € | ExpTech | EXP-R15-1053 | geliefert | https://www.exp-tech.de/zubehoer/sonstige/7387/heat-sink-thermal-tape-3m-8810-80mm-x-80mm
5V-Glättungskondensator | 5 | 0,98 € | 4,90 € | Mouser | 710-870135174006 | geliefert | https://www.mouser.de/ProductDetail/Wurth-Electronics/870135174006
I2C-Signal-Wandler-MOSFETs | 10 | 0,24 € | 2,43 € | Mouser | 512-BSS138 | geliefert | https://www.mouser.de/ProductDetail/ON-Semiconductor-Fairchild/BSS138?qs=sGAEpiMZZMvlOED0T0kTWl5MKyjMqq%2Fg
Plexiglasrohr 11cm | 2 | 8,64 € | 17,28 € | Plattenzuschnitt24 | C60000-RO3-080 | geliefert | https://www.plattenzuschnitt24.de/Plexiglas-XT-Rohr-3mm-farblos-80-74.html
Teensy 3.6 | 4 | 38,90 € | 155,60 € | Reichelt | TEENSY 3.6 | geliefert | https://www.reichelt.de/teensy-3-6-usb-teensy-3-6-p191458.html?&trstct=pos_0
Fan Connector | 6 | 0,30 € | 1,80 € | Reichelt | PS 25/2G BR | geliefert | https://www.reichelt.de/platinensteckverbinder-gerade-braun-2-polig-ps-25-2g-br-p38232.html
Siftleiste | 4 | 0,37 € | 1,48 € | Reichelt | SL 1X50G 2,54 | geliefert | https://www.reichelt.de/50pol-stiftleiste-gerade-rm-2-54-sl-1x50g-2-54-p19508.html?&trstct=pol_0
SMD Stiftleiste | 1 | 0,48 € | 0,48 € | Reichelt | SL 2X10G SMD2,54 | geliefert | https://www.reichelt.de/2x10pol-smd-stiftleiste-gerade-rm-2-54-sl-2x10g-smd2-54-p51717.html?trstct=pol_0
SMD Stiftleiste | 1 | 1,70 € | 1,70 € | Reichelt | SL 2X40G SMD2,54 | geliefert | https://www.reichelt.de/2x40pol-smd-stiftleiste-gerade-rm-2-54-sl-2x40g-smd2-54-p51725.html?trstct=pol_2
Buchsenleiste 1x20 | 14 | 0,27 € | 3,78 € | Reichelt | BL 1X20G8 2,54 | geliefert | https://www.reichelt.de/20pol-buchsenleiste-gerade-rm-2-54-h-8-5mm-bl-1x20g8-2-54-p51827.html?trstct=pol_0
Buchsenleiste 1x4 | 8 | 0,16 € | 1,28 € | Reichelt | MPE 094-1-004 | geliefert | https://www.reichelt.de/buchsenleisten-2-54-mm-1x04-gerade-mpe-094-1-004-p119913.html?&trstct=pol_1
Buchsenleiste 2x5 | 4 | 0,21 € | 0,84 € | Reichelt | RND 205-00654 | geliefert | https://www.reichelt.de/rnd-buchsenleiste-10-pol-rm-2-54-mm-rnd-205-00654-p208880.html?&trstct=pol_0
Buchsenleiste 2x4 | 4 | 0,26 € | 1,04 € | Reichelt | MPE 094-2-008 | geliefert | https://www.reichelt.de/sockets-2-54-mm-2x04-straight-mpe-094-2-008-p119928.html?&trstct=pol_0
Buchsenleiste 2x3 | 4 | 0,15 € | 0,60 € | Reichelt | RND 205-00652 | geliefert | https://www.reichelt.de/sockets-2-54-mm-1x05-straight-mpe-094-1-005-p119914.html?&trstct=pol_0
Buchsenleiste 1x5 | 4 | 0,22 € | 0,88 € | Reichelt | MPE 094-1-005 | geliefert | https://www.reichelt.de/rnd-buchsenleiste-5-pol-rm-2-54-mm-rnd-205-00645-p208871.html?&trstct=pol_0
Buchsenleiste 1x7 | 8 | 0,14 € | 1,12 € | Reichelt | RND 205-00647 | geliefert | https://www.reichelt.de/rnd-buchsenleiste-7-pol-rm-2-54-mm-rnd-205-00647-p208873.html?&trstct=pol_0
Fan | 4 | 1,65 € | 6,60 € | Reichelt | FAN-4010 12V | geliefert | https://www.reichelt.de/fan-12-v-dc-40-x-40-x-10-mm-rpm-5800-fan-4010-12v-p11004.html?r=1
Flachbandkabel | 1 | 2,90 € | 2,90 € | Reichelt | AWG 28-10G 3M | geliefert | https://www.reichelt.de/flachbandkabel-awg28-10-pol-grau-3m-ring-awg-28-10g-3m-p47637.html?trstct=pos_0
Flachband Buchse | 4 | 0,10 € | 0,40 € | Reichelt | PFL 10 | geliefert | https://www.reichelt.de/pfostenbuchse-10-polig-mit-zugentlastung-pfl-10-p14571.html?&trstct=pos_0
Flachband Stecker | 6 | 0,10 € | 0,60 € | Reichelt | WSL 10G | geliefert | https://www.reichelt.de/wannenstecker-10-polig-gerade-wsl-10g-p22816.html?&trstct=pos_0
SMD Diode | 6 | 0,14 € | 0,84 € | Reichelt | DO-214AC/SMA | geliefert | https://www.reichelt.de/gleichrichterdiode-100-v-2-a-do-214ac-sma-es-2ba-smd-p95406.html?trstct=pol_15
Kühlkörper (2x pro Chip) | 32 | 0,38 € | 12,16 € | Reichelt | ICK SMD A 13 SA | geliefert | https://www.reichelt.de/kuehlkoerper-smd-13-mm-alu-63-k-w-ick-smd-a-13-sa-p227833.html?&trstct=pol_7
Stiftleiste Spannungswandler | 1 | 1,10 € | 1,10 € | Reichelt | RND 205-00554 | geliefert | https://www.reichelt.de/stiftleiste-24-pol-gerade-rm-5-08-rnd-205-00554-p253027.html?trstct=pol_0&r=1
Sicherung 10 A (träge) | 10 | 0,09 € | 0,90 € | Reichelt | TR 10A | geliefert | https://www.reichelt.de/microfuse-5-x-20-mm-time-lag-10-a-tr-10a-p21793.html?r=1
2,4mm Megapixel Lens | 1 | 17,80 € | 17,80 € | VisionDimension | 302101 | bestellt | https://www.vision-dimension.com/de/objektive/mini-objektive/megapixel-miniobjektive/2-4mm-fisheye-1320-oeffnungswinkel-megapixel-board-lens-ir-format-1/3-s-m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
Micro USB Kabel Links gewinkelt | 2 | 4,69 € | 9,38 € | Amazon | CY Micro-USB-Host OTG-Kabel für Galaxy S4 i9500 N7100 i9220 i9100 XOOM, links abgewinkelt | geliefert | https://www.amazon.de/Micro-USB-Host-OTG-Kabel-Galaxy-i9500-abgewinkelt/dp/B00S6IQD9U
Micro USB Kabel Rechts gewinkelt | 2 | 3,80 € | 7,60 € | Amazon | Delock Kabel Micro USB Typ-B Stecker gewinkelt > USB 2.0-A Buchse OTG 11 cm | geliefert | https://www.amazon.de/Delock-Kabel-Stecker-gewinkelt-Buchse/dp/B006TCXLF4
Bodensensoren | 100 | 1,08 € | 108,00 € | Mouser | TSL2584TSV | Habemus | https://www.mouser.de/ProductDetail/985-TSL2584
Kondensator 0,1uF | 110 | 0,04 € | 4,29 € | Mouser | 710-885012207072 | Habemus | https://www.mouser.de/ProductDetail/Wurth-Electronics/885012207072
NeoPixel-Signal-Wandler | 10 | 0,23 € | 2,28 € | Mouser | 771-74HC1G125GW-G | Habemus | https://www.mouser.de/ProductDetail/Nexperia/74HC1G125GW125?qs=P62ublwmbi98oS26kHEtTw%3D%3D
 |  | Gesamt: | 608,22 €
 |  |  |  |  |  | bestellt
 |  |  |  |  |  | gliefert

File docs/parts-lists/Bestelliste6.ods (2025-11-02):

Artikel | Stückzahl | Einzelpreis | Gesamtpreis | Webshop | Artikelnummer | Status | Link
O-Ring; 4.0x1.0 | 17 | 0,27 € | 4,59 € | Hug-Technik | 4300400100 | geliefert | https://www.hug-technik.com/shop/product_info.php
O-Ring; 4.0x1.5 | 17 | 0,27 € | 4,59 € | Hug-Technik | 4300400150 | geliefert | https://www.hug-technik.com/shop/product_info.php
O-Ring; 4.5x1.0 | 17 | 0,27 € | 4,59 € | Hug-Technik | 4300450100 | geliefert | https://www.hug-technik.com/shop/product_info.php
O-Ring; 4.5x1.5 | 17 | 0,27 € | 4,59 € | Hug-Technik | 4300450150 | geliefert | https://www.hug-technik.com/shop/product_info.php
Sicherung 8A Flink 10 Stk. | 1 | 1,89 € | 1,89 € | Conrad | 524207 - 62 | geliefert | https://www.conrad.de/de/p/eska-520526-feinsicherung-x-l-5-mm-x-20-mm-8-a-250-v-flink-f-inhalt-10-st-524207.html
Sicherung 8A Mittelträge 10 Stk. | 1 | 1,98 € | 1,98 € | Conrad | 551040 - 62 | geliefert | https://www.conrad.de/de/p/eska-521026-feinsicherung-x-l-5-mm-x-20-mm-8-a-250-v-mitteltraege-mt-inhalt-10-st-551040.html
Messingdraht 2mm | 3 | 2,29 € | 6,87 € | Conrad | 297224 - 62 | geliefert | https://www.conrad.de/de/p/messing-rund-profil-x-l-2-mm-x-500-mm-1-st-297224.html
Litze Schwarz 5m 4mm² | 1 | 8,77 € | 8,77 € | Conrad | 605889 – 62 | geliefert | https://www.conrad.de/de/p/conrad-components-605889-fahrzeugleitung-flry-b-1-x-4-mm-schwarz-5-m-605889.html
Litze Rot 5m 4mm² | 1 | 8,40 € | 8,40 € | Conrad | 605865 – 62 | geliefert | https://www.conrad.de/de/p/conrad-components-605865-fahrzeugleitung-flry-b-1-x-4-mm-rot-5-m-605865.html
MOSFET Schuss neu | 6 | 0,99 € | 5,94 € | Reichelt | IRF 3708 | geliefert | https://www.reichelt.de/mosfet-n-ch-30v-62a-87w-to-220ab-irf-3708-p90229.html
Eventuell bestellen:
SLS Phantom 2700mAh 11.1V | 4 | 26,19 € | 104,76 € | SLS | SLSXT27003120 | nicht bestellt | https://www.stefansliposhop.de/Akkus/SLS-fuer-DJI-Yuneec/SLS-Phantom-I-2700mAh-3S1P-11-1V-20C-40C::1398.html
Kamera Flachbandkabel

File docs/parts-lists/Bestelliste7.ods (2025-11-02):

Artikel | Stückzahl | Einzelpreis | Gesamtpreis | Webshop | Artikelnummer | Status | Link
Kippschalter | 10 | 1,71 | 17,1 | Conrad | 1589425 - 62 | nicht bestellt | https://www.conrad.de/de/kippschalter-125-vac-1-x-einein-tru-components-tc-mk244z-rastend-1-st-1589425.htmlhttps://www.conrad.de/de/kippschalter-125-vac-1-x-e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
Messingdraht 2mm | 4 | 2,29 € | 9,16 € | Conrad | 297224 - 62 | nicht bestellt | https://www.conrad.de/de/p/messing-rund-profil-x-l-2-mm-x-500-mm-1-st-297224.html
Buchsenleiste 1x7 | 12 | 0,14 € | 1,68 € | Reichelt | RND 205-00647 | nicht bestellt | https://www.reichelt.de/rnd-buchsenleiste-7-pol-rm-2-54-mm-rnd-205-00647-p208873.html?&trstct=pol_0
Flachband Buchse | 2 | 0,10 € | 0,20 € | Reichelt | PFL 10 | nicht bestellt | https://www.reichelt.de/pfostenbuchse-10-polig-mit-zugentlastung-pfl-10-p14571.html?&trstct=pos_0
Flachband Stecker | 3 | 0,10 € | 0,30 € | Reichelt | WSL 10G | nicht bestellt | https://www.reichelt.de/wannenstecker-10-polig-gerade-wsl-10g-p22816.html?&trstct=pos_0
Buchsenleiste 1x20 | 8 | 0,27 € | 2,16 € | Reichelt | BL 1X20G8 2,54 | nicht bestellt | https://www.reichelt.de/20pol-buchsenleiste-gerade-rm-2-54-h-8-5mm-bl-1x20g8-2-54-p51827.html?trstct=pol_0
Buchsenleiste 1x4 | 6 | 0,16 € | 0,96 € | Reichelt | MPE 094-1-004 | nicht bestellt | https://www.reichelt.de/buchsenleisten-2-54-mm-1x04-gerade-mpe-094-1-004-p119913.html?&trstct=pol_1
Buchsenleiste 2x5 | 3 | 0,21 € | 0,63 € | Reichelt | RND 205-00654 | nicht bestellt | https://www.reichelt.de/rnd-buchsenleiste-10-pol-rm-2-54-mm-rnd-205-00654-p208880.html?&trstct=pol_0
Buchsenleiste 2x4 | 3 | 0,26 € | 0,78 € | Reichelt | MPE 094-2-008 | nicht bestellt | https://www.reichelt.de/sockets-2-54-mm-2x04-straight-mpe-094-2-008-p119928.html?&trstct=pol_0
Buchsenleiste 2x3 | 3 | 0,15 € | 0,45 € | Reichelt | RND 205-00652 | nicht bestellt | https://www.reichelt.de/rnd-buchsenleiste-6-pol-rm-2-54-mm-rnd-205-00652-p208878.html?&trstct=pol_0
Eventuell bestellen:
SLS Phantom 2700mAh 11.1V | 4 | 26,19 € | 104,76 € | SLS | SLSXT27003120 | nicht bestellt | https://www.stefansliposhop.de/Akkus/SLS-fuer-DJI-Yuneec/SLS-Phantom-I-2700mAh-3S1P-11-1V-20C-40C::1398.html
Kamera Flachbandkabel
Neopixel 5050 WS2812B – 10 Pack | 1 | 2,38 € | 2,38 € | ExpTech | EXP-R15-315 | nicht bestellt | https://www.exp-tech.de/zubehoer/led-leuchtmittel/5598/neopixel-5050-rgb-led-with-integrated-driver-chip-10-pack
Time of Flight Sensor | 1 | 11,38 € | 11,38 € | ExpTech | EXP-R25-1092 | nicht bestellt | https://www.exp-tech.de/en/sensors/distanceapproximation/8756/pololu-vl53l1x-time-of-flight-distance-sensor-carrier-with-voltage-regulator-400cm-max

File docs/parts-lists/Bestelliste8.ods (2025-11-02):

Bezeichnung | Beschreibung | Menge | Preis | Shop | Bestellnummer | Link
Raspi 4 | Performance(Pi4) > Performance(Tinker) & Tinker GPIO kaputt | 3 | 46,50 € | Reichelt | RASP PI 4 B 2GB | https://www.reichelt.de/raspberry-pi-4-b-4x-1-5-ghz-2-gb-ram-wlan-bt-rasp-pi-4-b-2gb-p259919.html?trstct=pol_5
Kühlkörper Raspi | Pi 4 läuft sehr warm, Lüfter sind schon am Roboter | 3 | 2,40 € | Reichelt | RPI MUSB USBC WT | https://www.reichelt.de/raspberry-pi-4-kuehlkoerper-40-x-30-x-5-mm-schwarz-rpi-cool-40x30-p261928.html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
USB-C / Micro USB Converter Pi | Bequemlichkeit, um Netzteile vom Tinker weiter verwenden zu können | 3 | 1,10 € | Reichelt | RPI COOL 40X30 | https://www.reichelt.de/raspberry-pi-adapter-microusb-auf-usb-c-weiss-rpi-musb-usbc-wt-p260033.html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
Teensy 3.6 | Ersatz Teensys, dritte Platine hat keine Teensys installiert, sodass jedes Bauteil direkt ausgetauscht werden könnte | 2 | 38,90 € | Reichelt | TEENSY 3.6 | https://www.reichelt.de/teensy-3-6-usb-teensy-3-6-p191458.html?&trstct=pos_0
Stiftleiste SMD für Teensy | Stiftleisten um Ersatz teensys zu ersetzen | 2 | 0,50 € | Reichelt | SL 2X10G SMD2,54 | https://www.reichelt.de/2x10pol-smd-stiftleiste-gerade-rm-2-54-sl-2x10g-smd2-54-p51717.html?trstct=pol_0
 |  | Gesamt: | 228,80 €

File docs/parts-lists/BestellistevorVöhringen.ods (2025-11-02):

Bezeichnung | Beschreibung | Menge | Preis | Gesamt | Shop | Bestellnummer | Link
Akku | größere Kapazität | 4 |  | 0,00 €
Klebeband | Dribblerbeschichtung | 1 |  | 0,00 €
PiCam (RPI JT CAM 5MP) | Kamera | 1 | 10,50 € | 10,50 € | Reichelt | RPI JT CAM 5MP | https://www.reichelt.de/raspberry-pi-kamera-5mp-inkl-stromversorgung-rpi-jt-cam-5mp-p218887.html?trstct=pos_0
Kabel für RasPi | Platinen-Verbindungskabel | 1 | 2,95 € | 2,95 € | Reichelt | DELOCK 85360 | https://www.reichelt.de/delock-kabel-power-4-pin-stecker-4-pin-buchse-pwm-10-cm-delock-85360-p220121.html
 |  | Gesamt: | 16,40 €
Druckteil | Benötigt | Bereits gedruckt
Akkuhalterung 1 | 1 | 1
Akkuhalterung 2 | 1 | 1
Akkustecker Halterung | 1 | 1
Innenraum Abdeckung Klappbar Links Hinten | 1 | 1
Innenraum Abdeckung Klappbar Rechts Hinten | 1 | 1
Innenraum Abdeckung Vorne | 1 | 1
Linsen Halterung | 1 | 1
Magnetsensor Halterung | 1 | 1
Platinen Abstandshalter Ring | 1 | 1
Platinenschutz Links Hinten | 1 | 1
Platinenschutz Rechts Hinten | 1 | 1
Platinenschutz Rad Hinten | 1 | 1
Platinenschutz Rad Links | 1 | 1
Platinenschutz Rad Rechts | 1 | 1
Platinenschutz Vorne | 1 | 1
TOF Halterung | 1 | 1
TOF Halterungszusatz Links | 1 | 1
TOF Halterungszusatz Rechts | 1 | 1
TOF Halterungszusatz Vorne | 1 | 1

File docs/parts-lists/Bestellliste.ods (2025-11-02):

Produkt-Name | Bestellnummer | Preis pro Stück | Anzahl | Link
Kurzschlussbrücke | 739550 – 62 | 0,58 € | 10 | https://www.conrad.de/de/kurzschlussbruecke-rastermass-254-mm-508-mm-polzahl-je-reihe2-w-p-products-265-101-10-00-inhalt-1-st-739550.html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
Motor-Treiber | 1573541 - 62 | 4,95 € | 4 | https://www.conrad.de/de/entwickler-platine-sbc-motodriver2-arduino-banana-pi-cubieboard-pcduino-raspberry-pi-raspberry-pi-2-b-raspberry-1573541.html
Foto-Widerstand (10pcs) | LDR GL5528 | 1,04 € | 2 | https://www.amazon.de/abh%C3%A4ngig-Widerstand-Fotowiderstand-Dependent-GL5528/dp/B00XDT8KI4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
LEDs | 1603079 - 62 | 0,12 € | 25 | https://www.conrad.de/de/led-bedrahtet-rot-rund-3-mm-125-mcd-60-20-ma-huiyuan-1603079.html
Vorwiderstände R130 | 1417736 - 62 | 0,06 € | 25 | https://www.conrad.de/de/kohleschicht-widerstand-130-axial-bedrahtet-0207-025-w-5-yageo-cfr-25jt-52-130r-1-st-1417736.html
O-Ringe | 4300900150 | 0,14 € | 120 | https://www.hug-technik.com/shop/product_info.php
Ultraschall (5pcs + 20 Kabel) | HC-SR04 | 9,99 € | 2 | https://www.amazon.de/Elegoo-HC-SR04-Ultraschallmodul-Distanzsensor-MEGA2560/dp/B01M9CMJ9O?s=ce-de
Kippschalter | 1589425 - 62 | 1,71 € | 10 | https://www.conrad.de/de/kippschalter-125-vac-1-x-einein-tru-components-tc-mk244z-rastend-1-st-1589425.html
Buchsenleiste | 1311507 - 62 | 0,99 € | 5 | https://www.conrad.de/de/buchsenleiste-praezision-anzahl-reihen-1-polzahl-je-reihe-10-econ-connect-mp70s10-1-st-1311507.html
Stiftleiste | 1390103 - 62 | 0,23 € | 15 | https://www.conrad.de/de/stiftleiste-standard-anzahl-reihen-1-polzahl-je-reihe-20-connfly-1390103-1-st-1390103.html
Akku-Stecker XT60 | 1373199 - 62 | 1,99 € | 4 | https://www.conrad.de/de/akku-stecker-xt60-vergoldet-1-st-reely-1373199.html
Motorkupplung | SODIAL(R) RC 3mm bis 5mm | 1,53 € | 4 | https://www.amazon.de/SODIAL-Flugzeug-Messing-Motorkupplung-Wellenkupplungen/dp/B01GNVRDR2
Flachbandkabel 1m 8-polig | 607378 – 62 | 2,67 € | 1 | https://www.conrad.de/de/flachbandkabel-rastermass-25-mm-8-x-023-mm-grau-lappkabel-49900045-meterware-607378.html
Kompasssensor | GY - 9250 MPU-9250 | 4,85 € | 4 = 1*Test + 3*Echt | https://www.gearbest.com/sensors/pp_244846.html?wid=1433363&currency=EUR&vip=4446208
GESAMT: |  | 130,61 €
fehlt:
Schuss besser überlegen
Dribbler „kalibrieren“

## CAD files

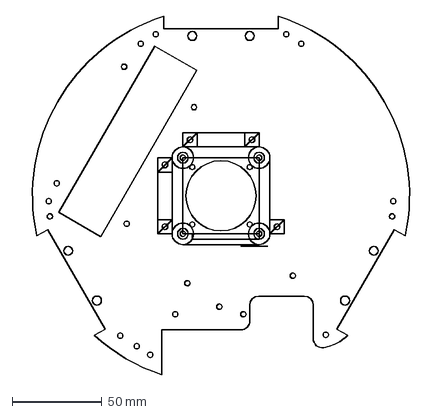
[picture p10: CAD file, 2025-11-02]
mechanical/3d-models/dxf/Platine2Halterung2.dxf
228.2 x 199.7 mm

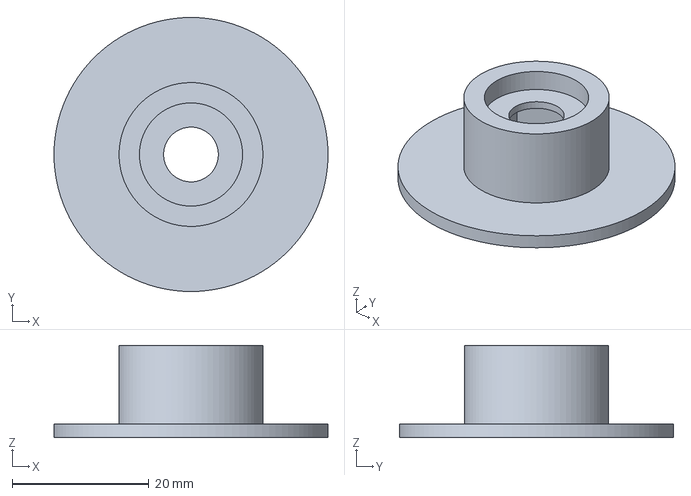
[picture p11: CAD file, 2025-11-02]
mechanical/3d-models/gcode/NummerPlatte.3mf
40.0 x 40.0 x 13.5 mm

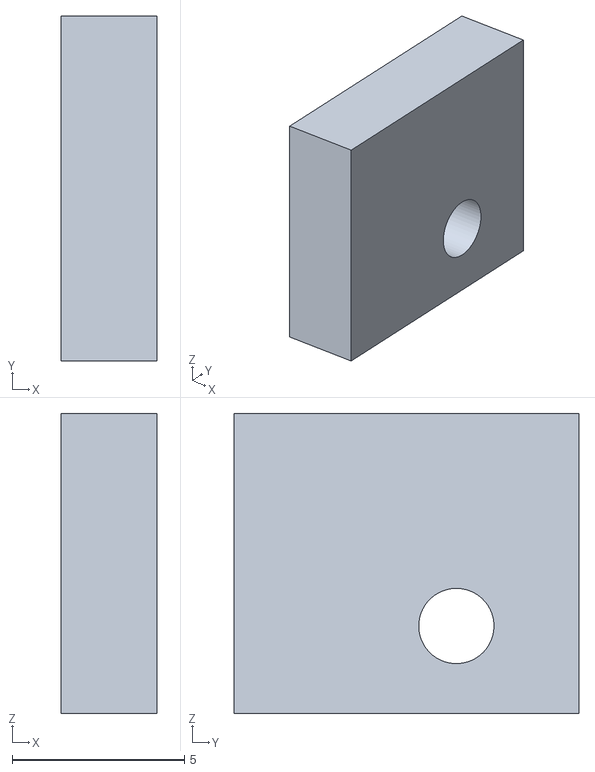
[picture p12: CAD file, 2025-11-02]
mechanical/3d-models/stl/TOF_HalterungszusatzRechts.stl
2.79 x 10.0 x 8.71

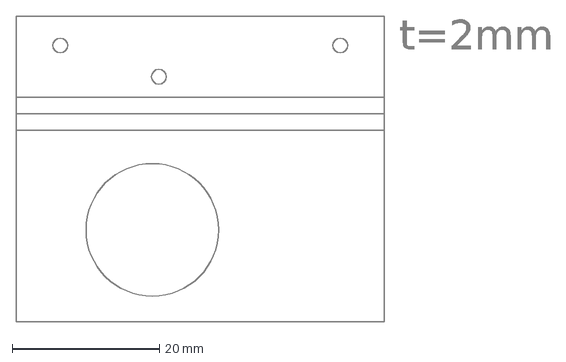
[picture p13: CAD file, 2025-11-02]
mechanical/metal-fabrication/dribbler/Abwicklung Schussaufnahme.dxf
t=2mm

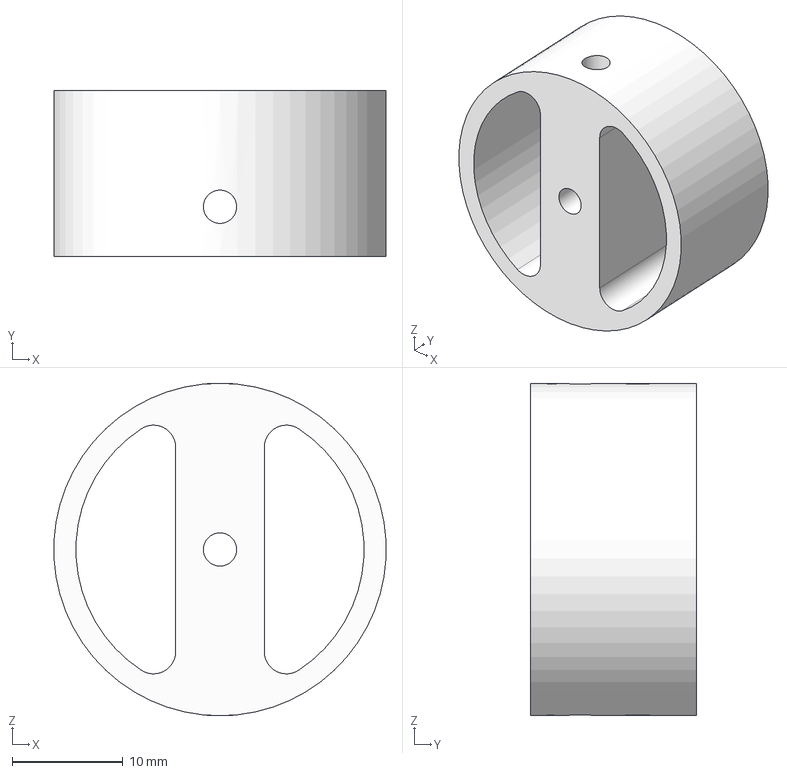
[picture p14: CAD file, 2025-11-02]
mechanical/metal-fabrication/dribbler/Dribbler/DribblerRad.step
30.0 x 15.0 x 30.0 mm

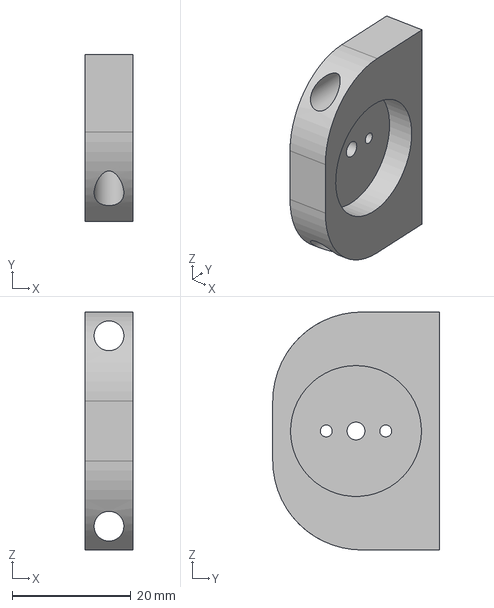
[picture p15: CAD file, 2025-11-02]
mechanical/metal-fabrication/motor-mounts/Motorhalterung.step
8.00 x 28.0 x 40.0 mm

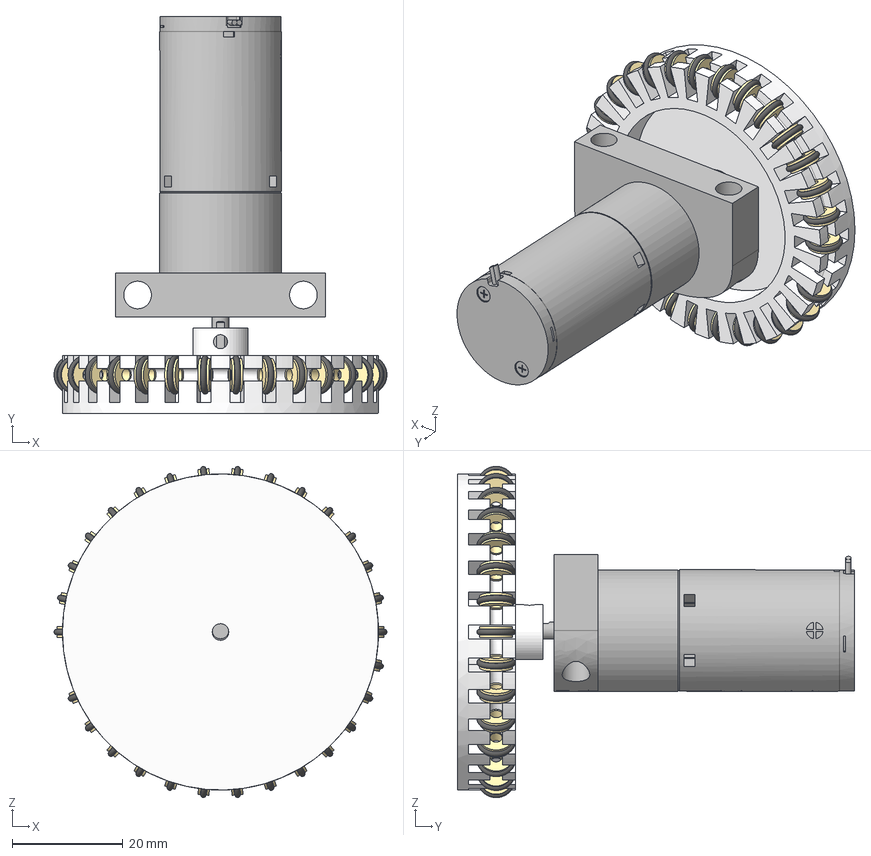
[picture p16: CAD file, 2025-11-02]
mechanical/metal-fabrication/wheel/Monowheel-Step-Datei.step
60.2 x 71.8 x 59.9 mm
Minirad-7mm (mit o-ring 7mm) x 29
110356_GP22B_0_15NM_2ST_SL
139838_Amax22_EB_5W_SL_1WE_K
Komponente1

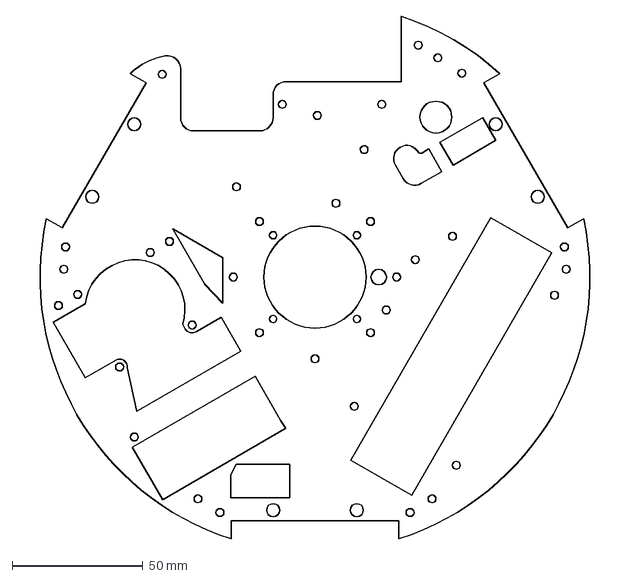
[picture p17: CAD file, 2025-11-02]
mechanical/3d-models/dxf/MittelplatteTest.dxf
228.2 x 199.7 mm

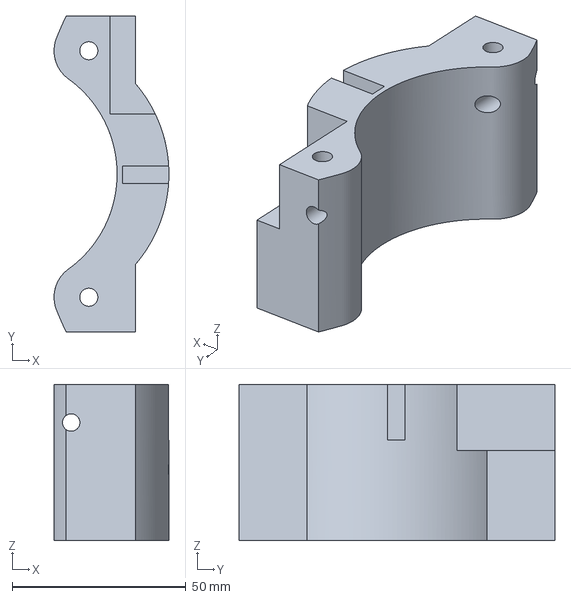
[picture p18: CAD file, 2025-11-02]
mechanical/3d-models/gcode/DribblerTestDruck.3mf
33.1 x 90.9 x 45.0 mm

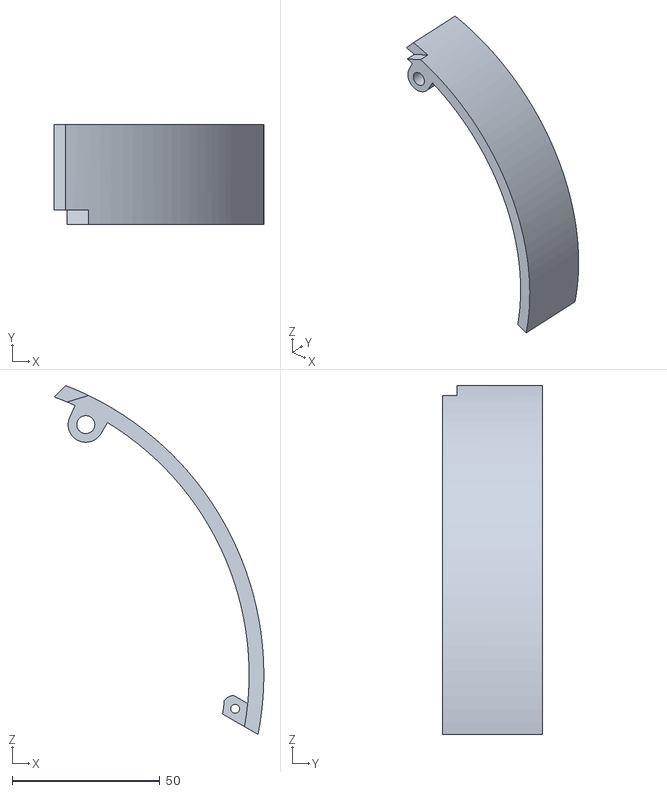
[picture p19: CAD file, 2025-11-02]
mechanical/3d-models/stl/InnenraumAbdeckungKlappbarRechtsHinten.stl
71.0 x 34.0 x 118.2

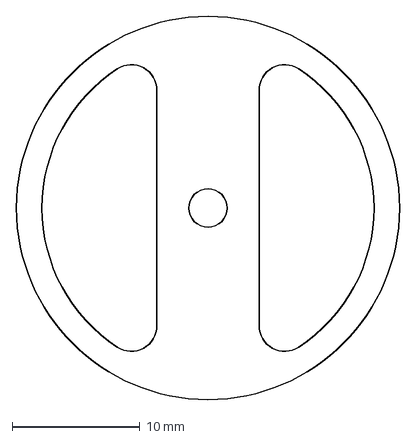
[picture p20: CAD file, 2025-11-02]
mechanical/metal-fabrication/dribbler/Dribbler/DribblerRadGrundform.dxf
30.0 x 30.0 mm

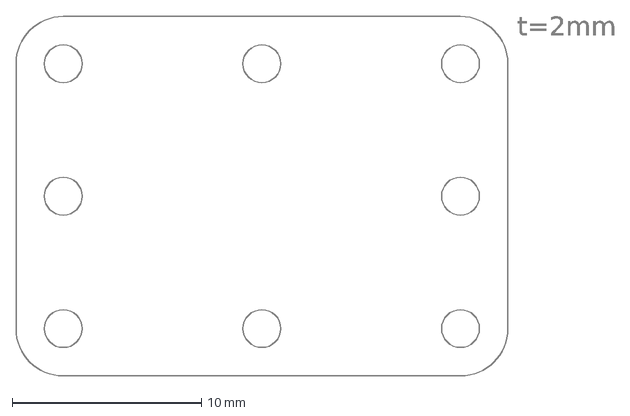
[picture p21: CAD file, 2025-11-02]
mechanical/metal-fabrication/dribbler/Kammerahalterung.dxf
t=2mm

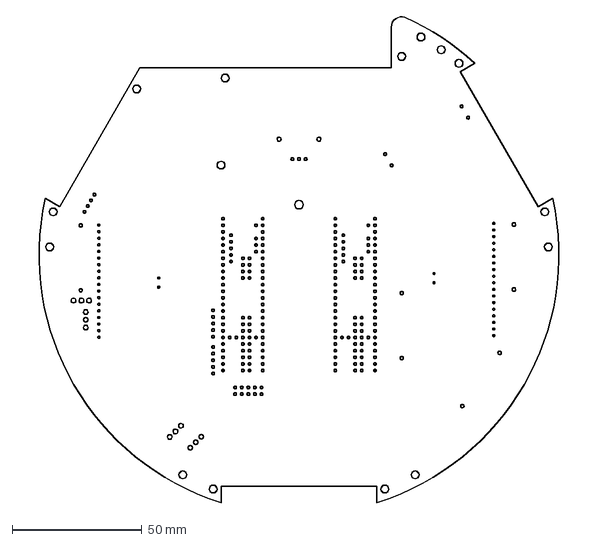
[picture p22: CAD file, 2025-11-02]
mechanical/3d-models/dxf/PlatineV3.dxf
217.8 x 187.1 mm

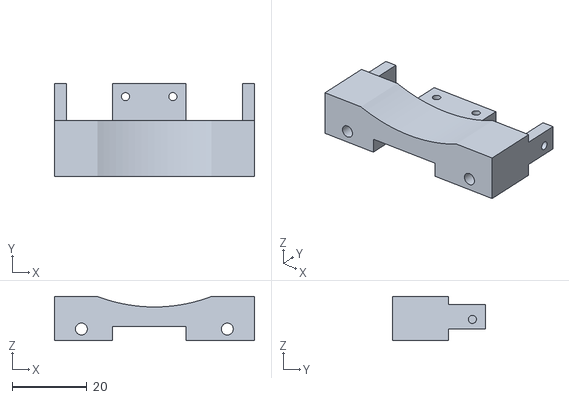
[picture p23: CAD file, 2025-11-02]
mechanical/3d-models/stl/TOF_Halterung.stl
53.6 x 25.0 x 11.9

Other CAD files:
mechanical/metal-fabrication/dribbler/Bumper links.dxf
mechanical/3d-models/dxf/SchussLoch.dxf
mechanical/3d-models/stl/V2InnenraumAbdeckungKlappbarRechtsHinten.stl
mechanical/metal-fabrication/dribbler/Rad.dxf
mechanical/3d-models/cad/DribblerRad.f3d
mechanical/3d-models/cad/DribblertestModelLego.obj
mechanical/3d-models/dxf/GrundrissKamerahalterungNeu.dxf
mechanical/3d-models/dxf/GrundrissTOFPlatine.dxf
mechanical/3d-models/dxf/Kamerahalterung.dxf
mechanical/3d-models/dxf/KamerahalterungAenderung1.dxf
mechanical/3d-models/dxf/Platine2Aenderung1.dxf
mechanical/3d-models/dxf/Platine2Aenderung2.dxf
mechanical/3d-models/dxf/Platine2Halterung1.dxf
mechanical/3d-models/dxf/PlatineTofNeu.dxf
mechanical/3d-models/dxf/PlatineTofNeuAenderungen1.dxf
mechanical/3d-models/dxf/PlatinenGrundriss.dxf
mechanical/3d-models/dxf/PlatinenGrundrissAenderung.dxf
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

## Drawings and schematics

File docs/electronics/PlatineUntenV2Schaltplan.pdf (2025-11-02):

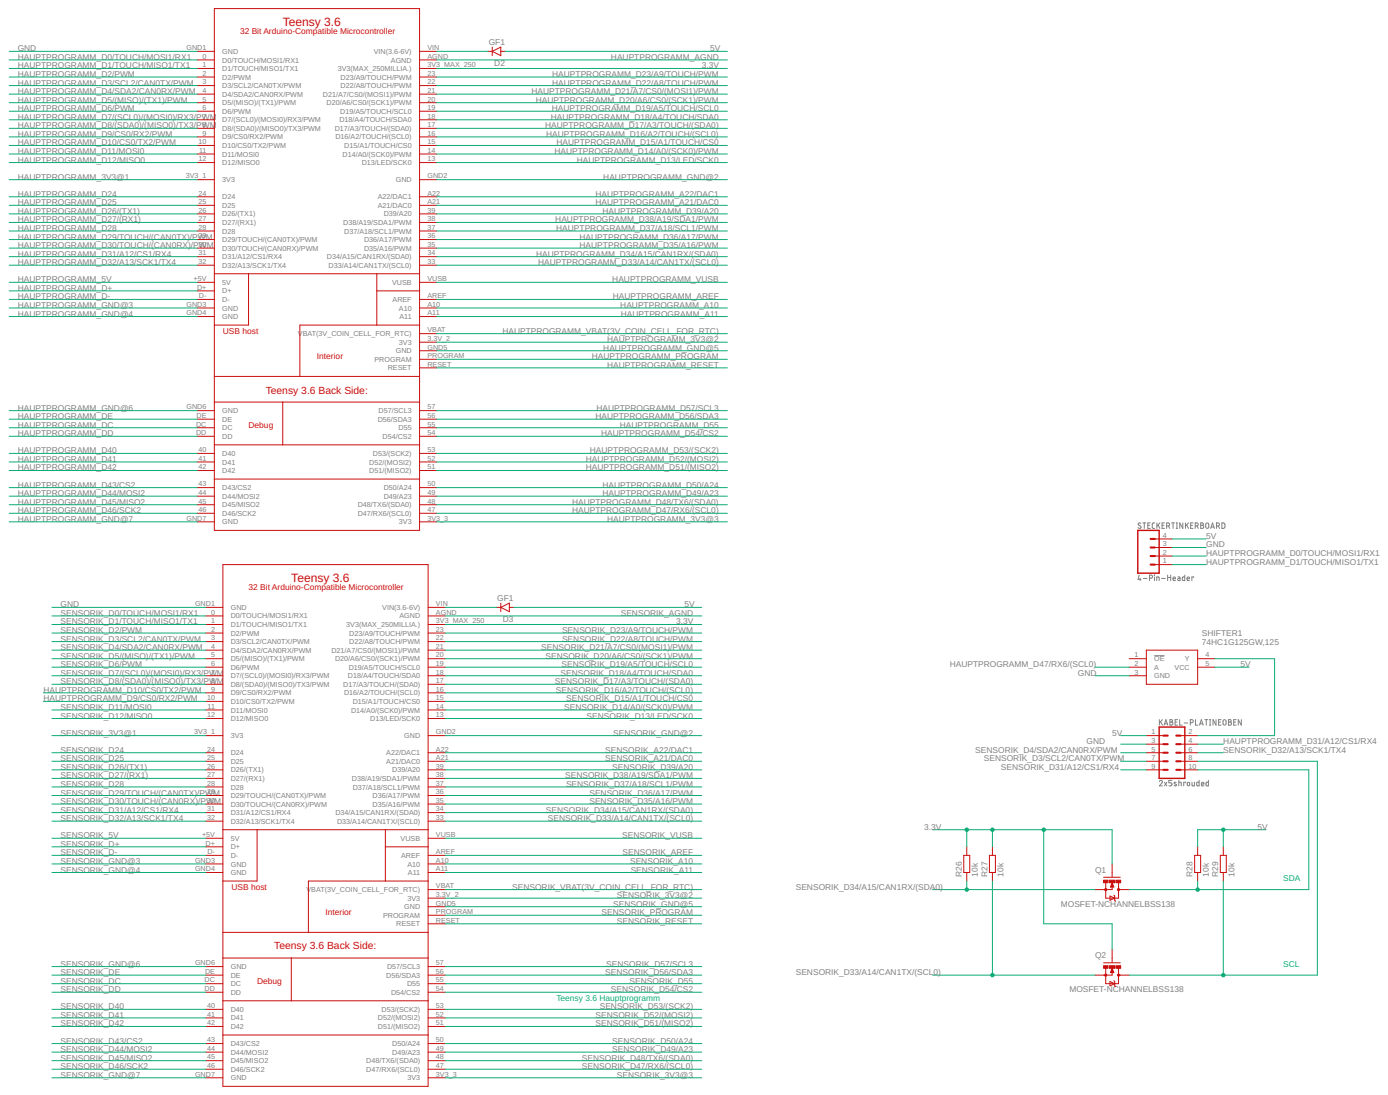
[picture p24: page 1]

32 Bit Arduino-Compatible Microcontroller

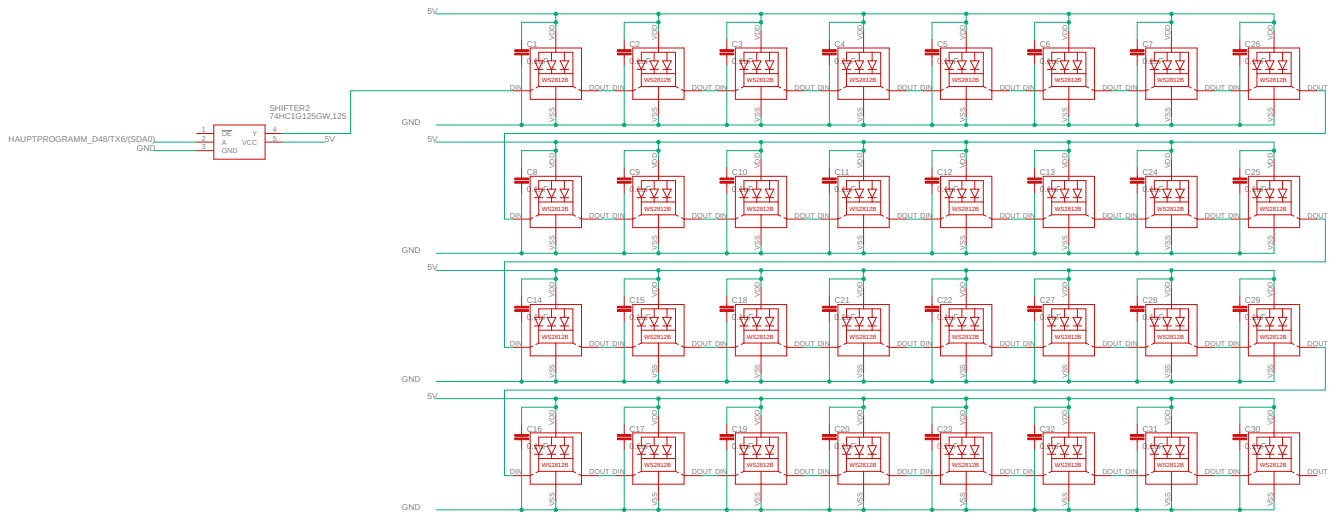
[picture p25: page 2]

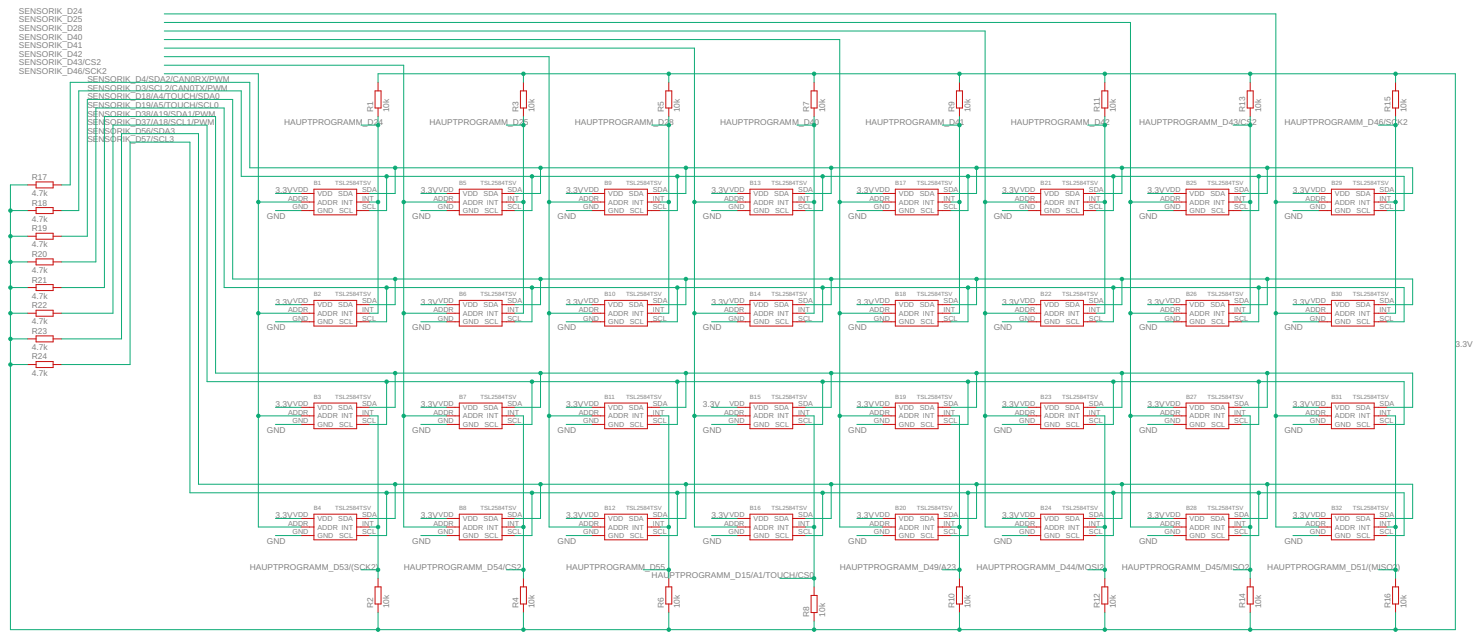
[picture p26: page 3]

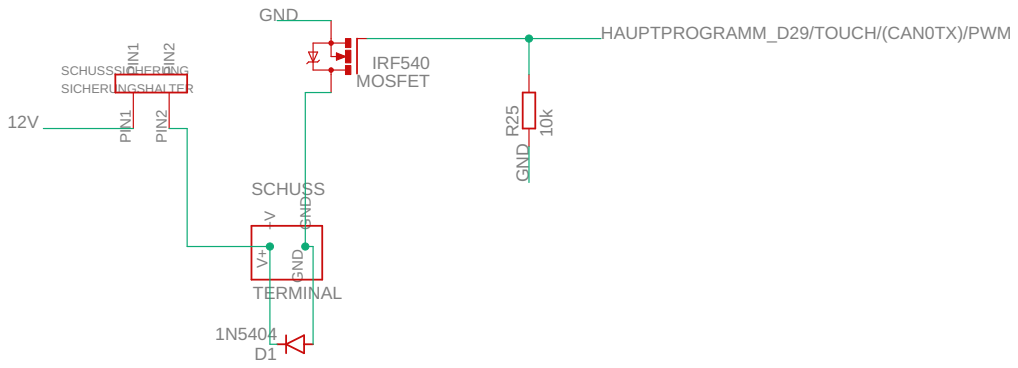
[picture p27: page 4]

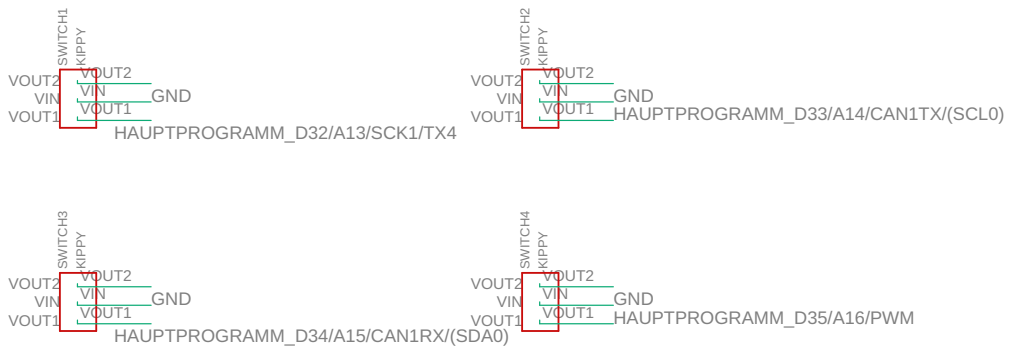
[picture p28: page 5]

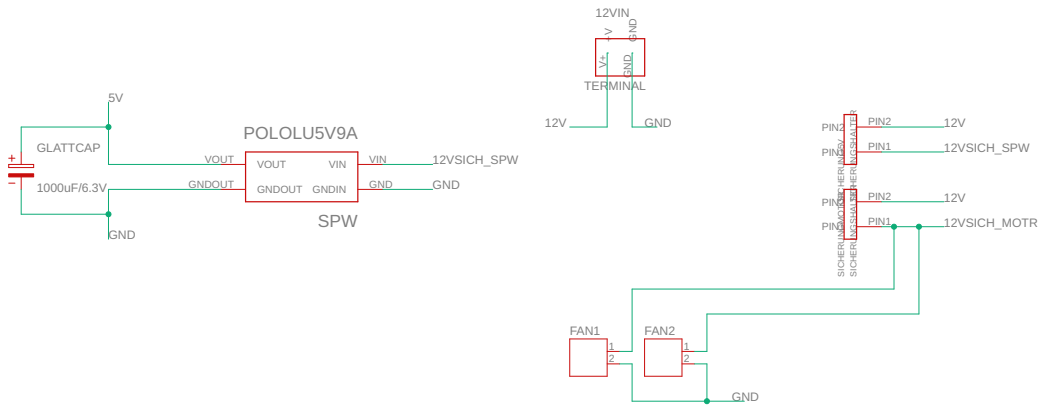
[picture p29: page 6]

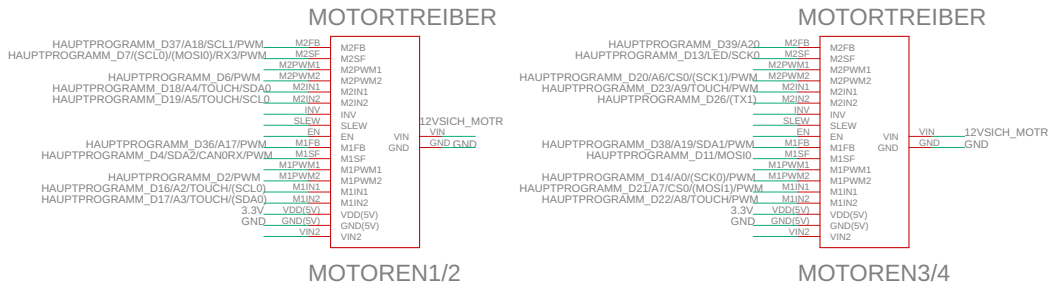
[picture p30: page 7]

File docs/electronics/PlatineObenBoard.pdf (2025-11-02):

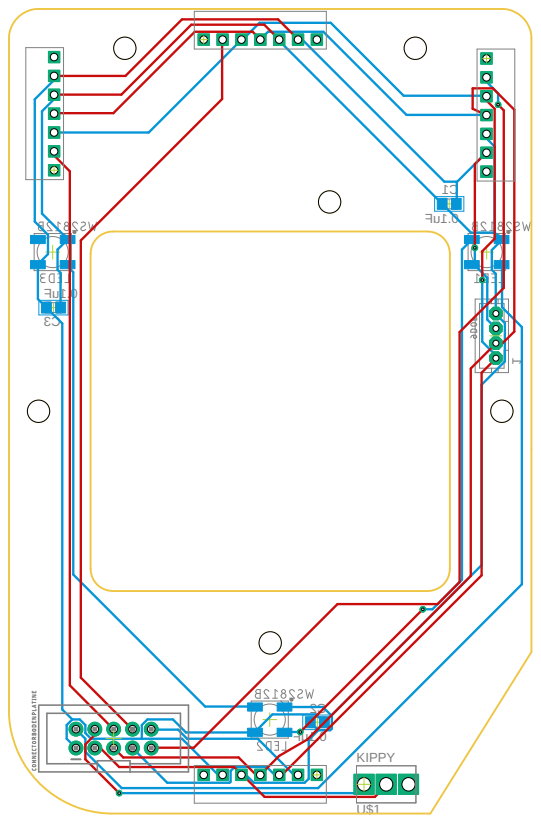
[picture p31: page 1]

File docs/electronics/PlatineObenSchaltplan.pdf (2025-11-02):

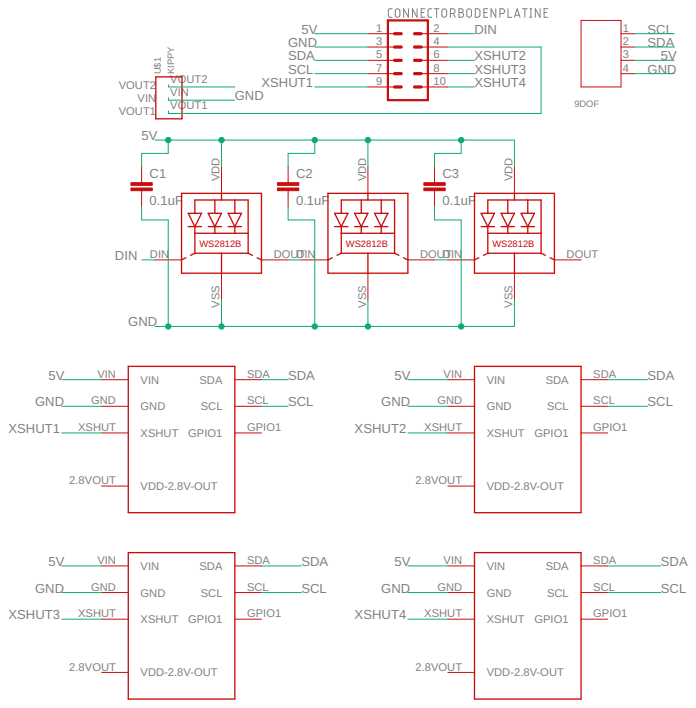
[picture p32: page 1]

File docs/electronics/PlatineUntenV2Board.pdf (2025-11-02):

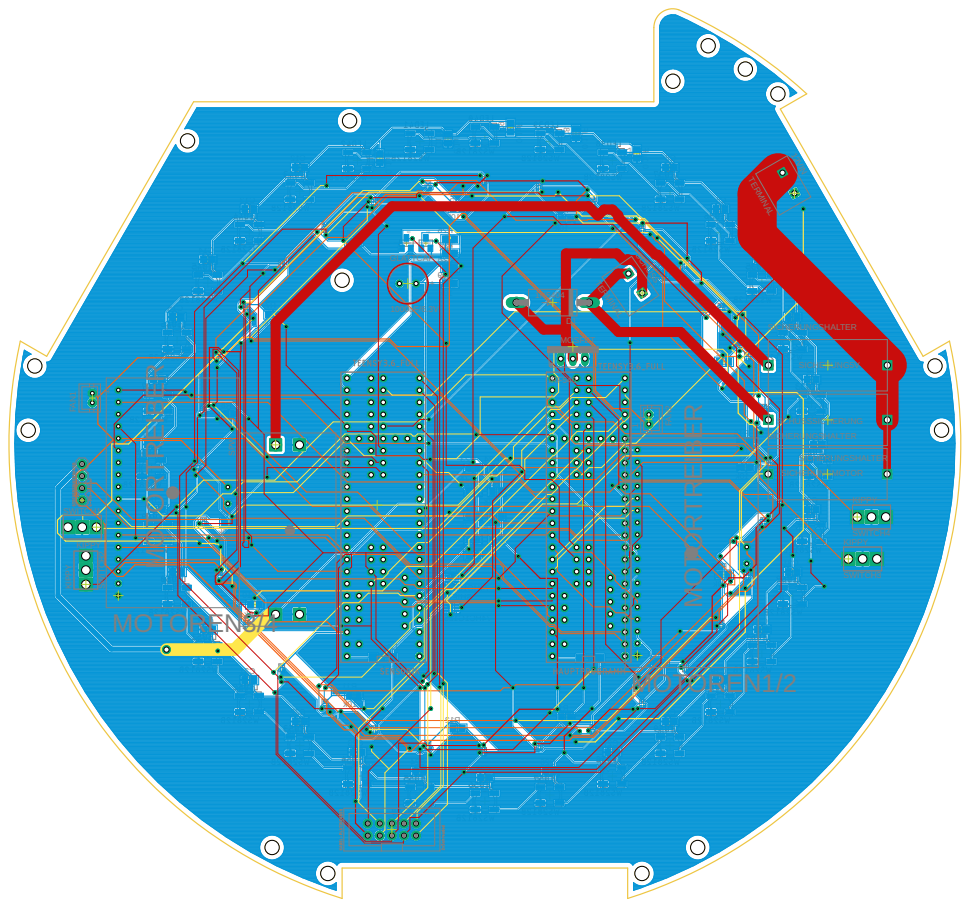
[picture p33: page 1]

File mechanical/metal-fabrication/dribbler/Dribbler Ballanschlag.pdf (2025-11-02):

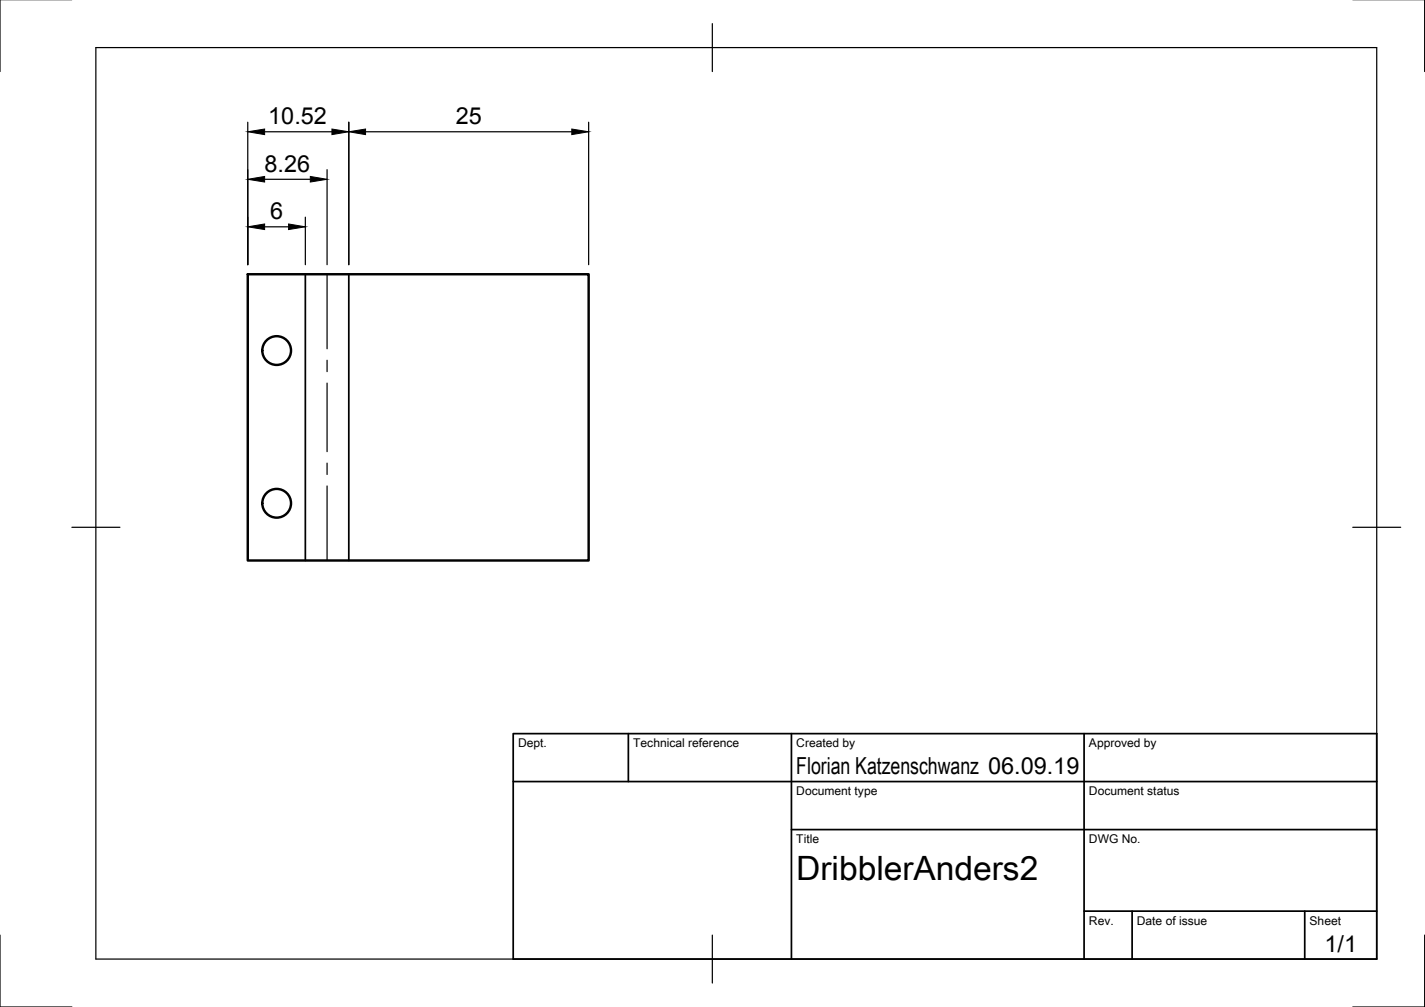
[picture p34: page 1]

Dept. | Technical reference | Created by Florian Katzenschwanz 06.09.19 | Approved by

Document type | Document status

Title DribblerAnders2 | DWG No.

Rev. | Date of issue | Sheet 1/1

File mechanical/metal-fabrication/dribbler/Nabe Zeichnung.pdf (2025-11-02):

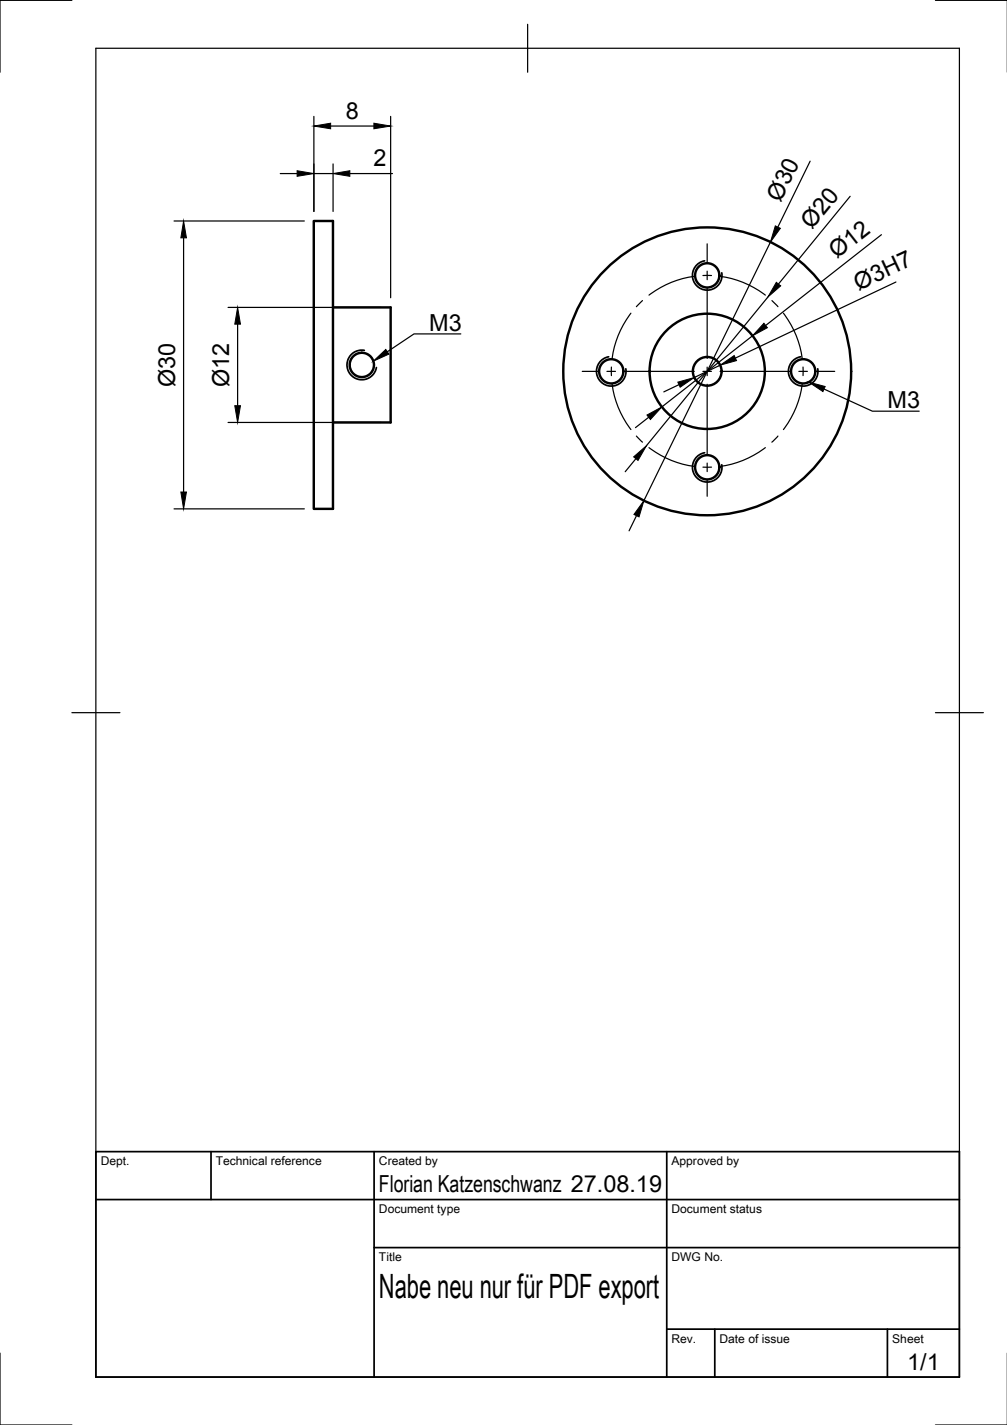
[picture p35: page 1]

Dept. | Technical reference | Created by Florian Katzenschwanz 27.08.19 | Approved by

Document type | Document status

Title Nabe neu nur für PDF export | DWG No.

Rev. | Date of issue | Sheet 1/1

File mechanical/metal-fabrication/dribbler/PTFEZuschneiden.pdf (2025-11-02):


Dept. | Technical reference | Created by Börning Schortsörkit 08.11.2019 | Approved by

Document type | Document status

Title BlechDribbler | DWG No.

Rev. | Date of issue | Sheet 1/1

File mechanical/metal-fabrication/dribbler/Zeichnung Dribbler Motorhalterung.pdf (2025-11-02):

Florian Katzenschwanz 22.46

Dept. | Technical reference | Created by 06.09.19 | Approved by

Document type | Document status

Title DribblerAnders2 | DWG No.

Rev. | Date of issue | Sheet 1/1

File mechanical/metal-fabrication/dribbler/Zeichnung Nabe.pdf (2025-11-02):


Dept. | Technical reference | Created by Florian Katzenschwanz 24.06.19 | Approved by

Document type | Document status

Title Nabe neu nur für PDF export | DWG No.

Rev. | Date of issue | Sheet 1/1

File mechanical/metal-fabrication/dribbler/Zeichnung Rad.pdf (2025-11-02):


Dept. | Technical reference | Created by Florian Katzenschwanz 28.08.19 | Approved by

Document type | Document status

Title Rad zweiteilig neu | DWG No.

Rev. | Date of issue | Sheet 1/1

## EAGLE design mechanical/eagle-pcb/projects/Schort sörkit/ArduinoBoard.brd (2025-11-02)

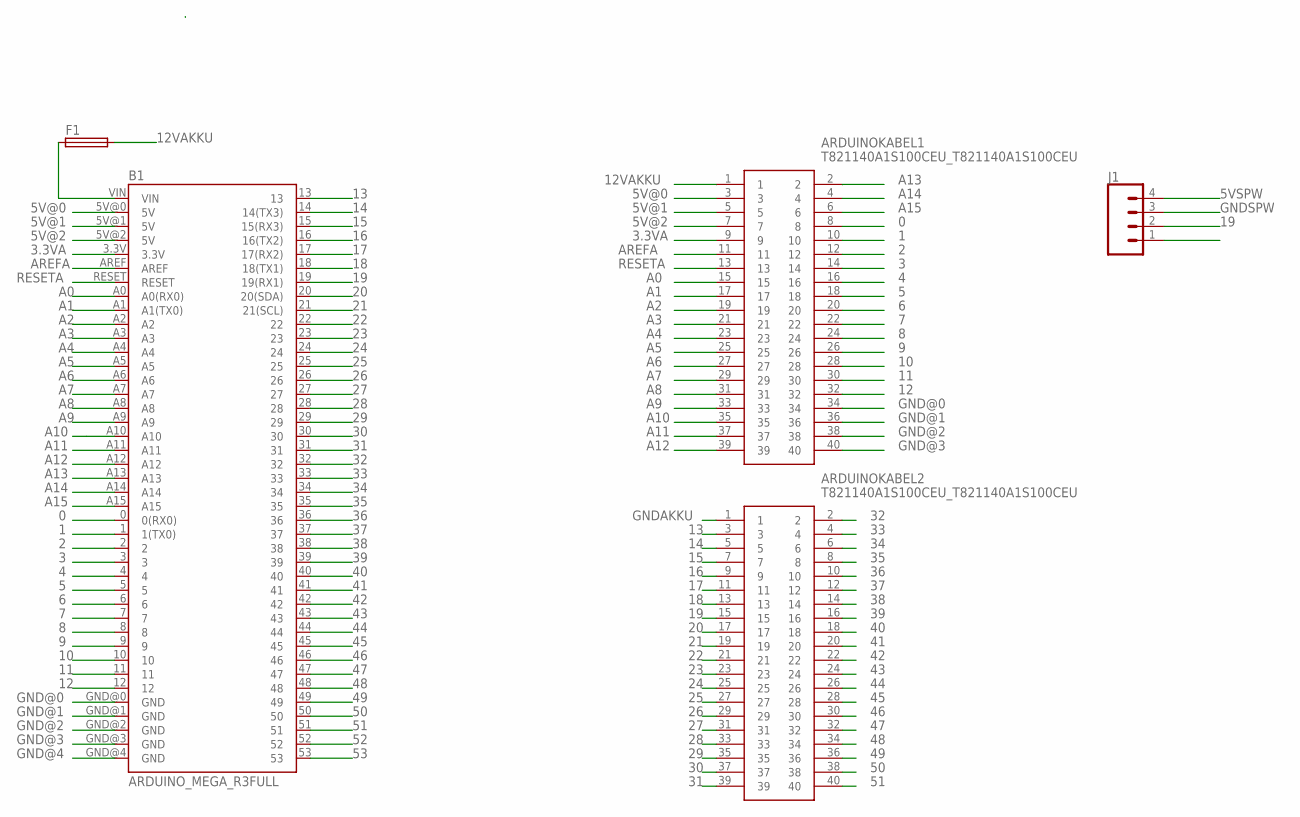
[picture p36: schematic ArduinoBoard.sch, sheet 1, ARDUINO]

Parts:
ARDUINOKABEL1, ARDUINOKABEL2: T821140A1S100CEU_T821140A1S100CEU; T821140A1S100CEU_SHDR40W64P254X254_2X20_5842X89
B1: ARDUINO_MEGA_R3FULL; ARDUINO_MEGA
F1: SH25
J1: CONN_04; 1X04

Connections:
0: ARDUINOKABEL1.8, B1.0 (0(RX0))
1: ARDUINOKABEL1.10, B1.1 (1(TX0))
2: ARDUINOKABEL1.12, B1.2; also elsewhere on the board
3: ARDUINOKABEL1.14, B1.3; also elsewhere on the board
3.3VA: ARDUINOKABEL1.9, B1.3.3V
4: ARDUINOKABEL1.16, B1.4; also elsewhere on the board
5: ARDUINOKABEL1.18, B1.5; also elsewhere on the board
5V@0: ARDUINOKABEL1.3, B1.5V@0 (5V); also elsewhere on the board
5V@1: ARDUINOKABEL1.5, B1.5V@1 (5V)
5V@2: ARDUINOKABEL1.7, B1.5V@2 (5V)
6: ARDUINOKABEL1.20, B1.6; also elsewhere on the board
7: ARDUINOKABEL1.22, B1.7
8: ARDUINOKABEL1.24, B1.8; also elsewhere on the board
9: ARDUINOKABEL1.26, B1.9
10: ARDUINOKABEL1.28, B1.10
11: ARDUINOKABEL1.30, B1.11
12: ARDUINOKABEL1.32, B1.12
12VAKKU: ARDUINOKABEL1.1, F1.2
13: ARDUINOKABEL2.3, B1.13
14: ARDUINOKABEL2.5, B1.14 (14(TX3))
15: ARDUINOKABEL2.7, B1.15 (15(RX3))
16: ARDUINOKABEL2.9, B1.16 (16(TX2))
17: ARDUINOKABEL2.11, B1.17 (17(RX2))
18: ARDUINOKABEL2.13, B1.18 (18(TX1)); also elsewhere on the board
19: ARDUINOKABEL2.15, B1.19 (19(RX1)), J1.2; also elsewhere on the board
20: ARDUINOKABEL2.17, B1.20 (20(SDA))
21: ARDUINOKABEL2.19, B1.21 (21(SCL))
22: ARDUINOKABEL2.21, B1.22
23: ARDUINOKABEL2.23, B1.23
24: ARDUINOKABEL2.25, B1.24
25: ARDUINOKABEL2.27, B1.25
26: ARDUINOKABEL2.29, B1.26
27: ARDUINOKABEL2.31, B1.27
28: ARDUINOKABEL2.33, B1.28
29: ARDUINOKABEL2.35, B1.29
30: ARDUINOKABEL2.37, B1.30
31: ARDUINOKABEL2.39, B1.31
32: ARDUINOKABEL2.2, B1.32
33: ARDUINOKABEL2.4, B1.33
34: ARDUINOKABEL2.6, B1.34
35: ARDUINOKABEL2.8, B1.35
36: ARDUINOKABEL2.10, B1.36
37: ARDUINOKABEL2.12, B1.37
38: ARDUINOKABEL2.14, B1.38
39: ARDUINOKABEL2.16, B1.39
40: ARDUINOKABEL2.18, B1.40
41: ARDUINOKABEL2.20, B1.41
42: ARDUINOKABEL2.22, B1.42
43: ARDUINOKABEL2.24, B1.43
44: ARDUINOKABEL2.26, B1.44
45: ARDUINOKABEL2.28, B1.45
46: ARDUINOKABEL2.30, B1.46
47: ARDUINOKABEL2.32, B1.47
48: ARDUINOKABEL2.34, B1.48
49: ARDUINOKABEL2.36, B1.49
50: ARDUINOKABEL2.38, B1.50
51: ARDUINOKABEL2.40, B1.51
52: B1.52
53: B1.53
A0: ARDUINOKABEL1.15, B1.A0 (A0(RX0))
A1: ARDUINOKABEL1.17, B1.A1 (A1(TX0))
A2: ARDUINOKABEL1.19, B1.A2
A3: ARDUINOKABEL1.21, B1.A3
A4: ARDUINOKABEL1.23, B1.A4
A5: ARDUINOKABEL1.25, B1.A5
A6: ARDUINOKABEL1.27, B1.A6
A7: ARDUINOKABEL1.29, B1.A7
A8: ARDUINOKABEL1.31, B1.A8
A9: ARDUINOKABEL1.33, B1.A9
A10: ARDUINOKABEL1.35, B1.A10
A11: ARDUINOKABEL1.37, B1.A11
A12: ARDUINOKABEL1.39, B1.A12
A13: ARDUINOKABEL1.2, B1.A13
A14: ARDUINOKABEL1.4, B1.A14
A15: ARDUINOKABEL1.6, B1.A15
AREFA: ARDUINOKABEL1.11, B1.AREF
GND@0: ARDUINOKABEL1.34, B1.GND@0 (GND); also elsewhere on the board
GND@1: ARDUINOKABEL1.36, B1.GND@1 (GND)
GND@2: ARDUINOKABEL1.38, B1.GND@2 (GND)
GND@3: ARDUINOKABEL1.40, B1.GND@3 (GND)
GND@4: B1.GND@4 (GND)
GNDAKKU: ARDUINOKABEL2.1
RESETA: ARDUINOKABEL1.13, B1.RESET
VIN: B1.VIN, F1.1

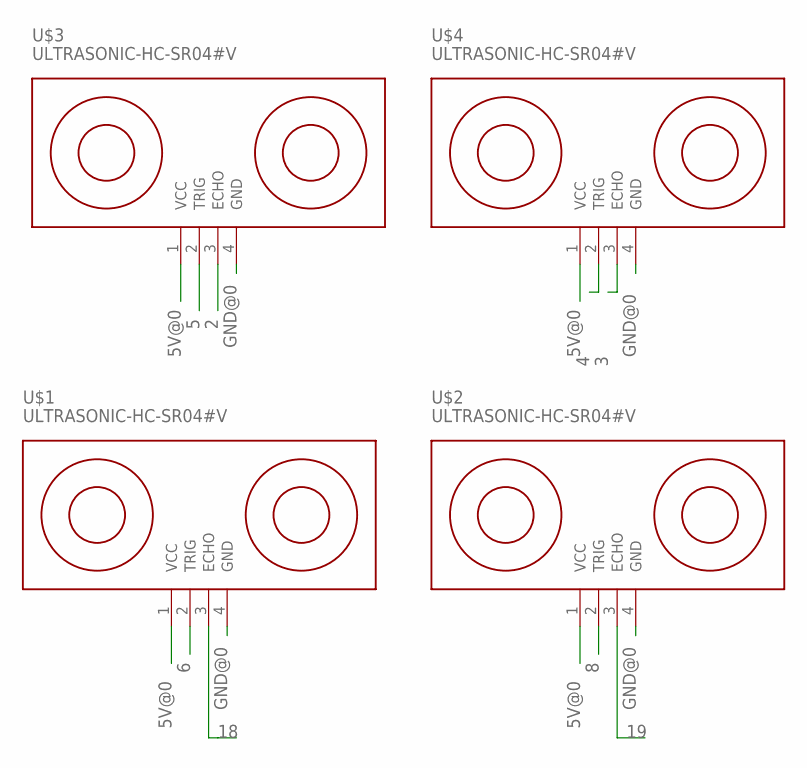
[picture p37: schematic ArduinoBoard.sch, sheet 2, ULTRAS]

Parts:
U$1, U$2, U$3, U$4: ULTRASONIC-HC-SR04#V

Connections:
2: U$3.3 (ECHO); also elsewhere on the board
3: U$4.3 (ECHO); also elsewhere on the board
4: U$4.2 (TRIG); also elsewhere on the board
5: U$3.2 (TRIG); also elsewhere on the board
5V@0: U$1.1 (VCC), U$2.1 (VCC), U$3.1 (VCC), U$4.1 (VCC); also elsewhere on the board
6: U$1.2 (TRIG); also elsewhere on the board
8: U$2.2 (TRIG); also elsewhere on the board
18: U$1.3 (ECHO); also elsewhere on the board
19: U$2.3 (ECHO); also elsewhere on the board
GND@0: U$1.4 (GND), U$2.4 (GND), U$3.4 (GND), U$4.4 (GND); also elsewhere on the board

Board: 2 copper layers, 9 parts (0 on the bottom side), 80 nets, no tracks yet.

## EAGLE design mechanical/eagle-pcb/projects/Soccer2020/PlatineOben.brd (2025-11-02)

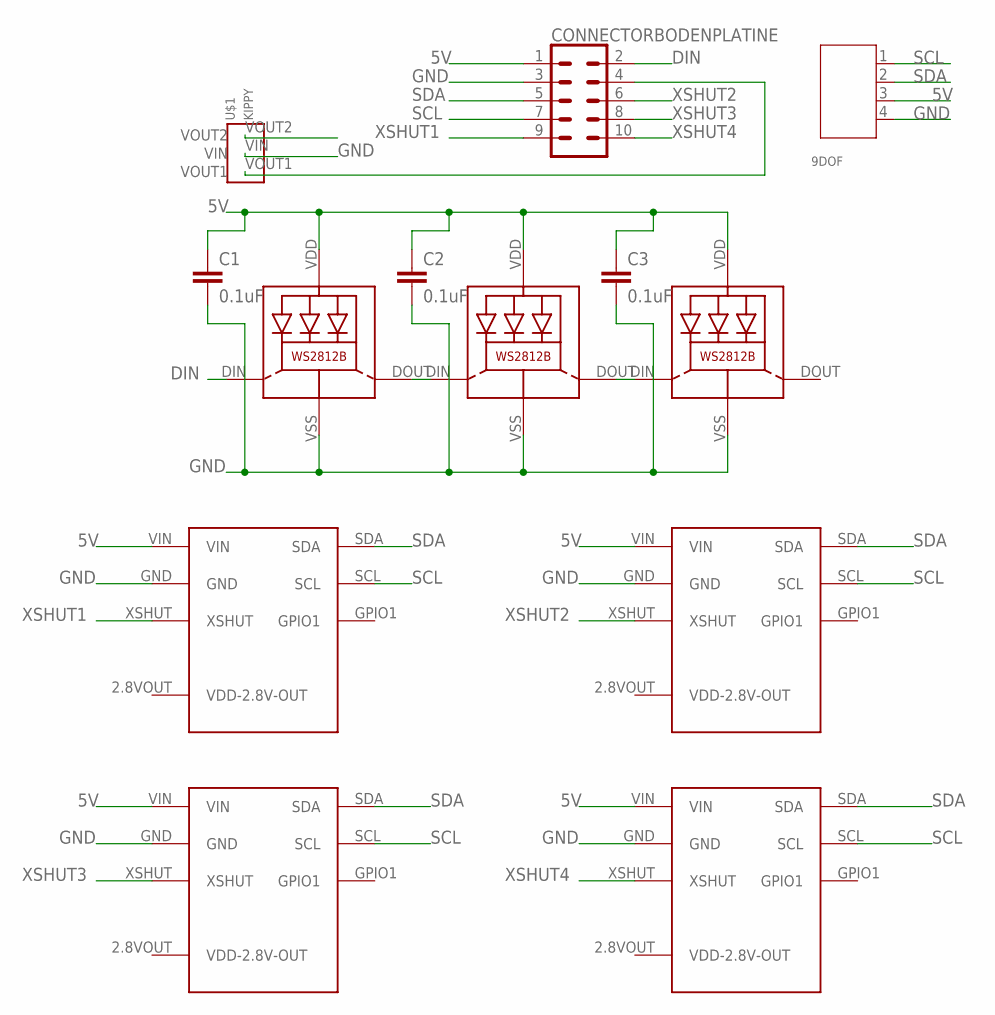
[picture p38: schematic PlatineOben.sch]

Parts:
9DOF: 4P-2.0; JST-PH4
C1, C2, C3: 0.1uF; C0805
CONNECTORBODENPLATINE: CONN_05X2; 2X5-SHROUDED(3D)
LED1, LED2, LED3: WS2812B
TOFH: TOFPOLOLUSTEHEND; TOFPOLOLU_STEHEND
TOFL: TOFPOLOLUSTEHEND; TOFPOLOLU_STEHEND
TOFR: TOFPOLOLUSTEHEND; TOFPOLOLU_STEHEND
TOFV: TOFPOLOLUSTEHEND; TOFPOLOLU_STEHEND
U$1: KIPPY

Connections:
5V: 9DOF.3, C1.1, C2.1, C3.1, CONNECTORBODENPLATINE.1, LED1.VDD, LED2.VDD, LED3.VDD, TOFH.VIN, TOFL.VIN, TOFR.VIN, TOFV.VIN
DIN: CONNECTORBODENPLATINE.2, LED1.DIN (DI)
GND: 9DOF.4, C1.2, C2.2, C3.2, CONNECTORBODENPLATINE.3, LED1.VSS (GND), LED2.VSS (GND), LED3.VSS (GND), TOFH.GND, TOFL.GND, TOFR.GND, TOFV.GND, U$1.VIN
unnamed: CONNECTORBODENPLATINE.4, U$1.VOUT1
unnamed: LED1.DOUT (DO), LED2.DIN (DI)
unnamed: LED2.DOUT (DO), LED3.DIN (DI)
SCL: 9DOF.1, CONNECTORBODENPLATINE.7, TOFH.SCL, TOFL.SCL, TOFR.SCL, TOFV.SCL
SDA: 9DOF.2, CONNECTORBODENPLATINE.5, TOFH.SDA, TOFL.SDA, TOFR.SDA, TOFV.SDA
XSHUT1: CONNECTORBODENPLATINE.9, TOFR.XSHUT
XSHUT2: CONNECTORBODENPLATINE.6, TOFL.XSHUT
XSHUT3: CONNECTORBODENPLATINE.8, TOFV.XSHUT
XSHUT4: CONNECTORBODENPLATINE.10, TOFH.XSHUT

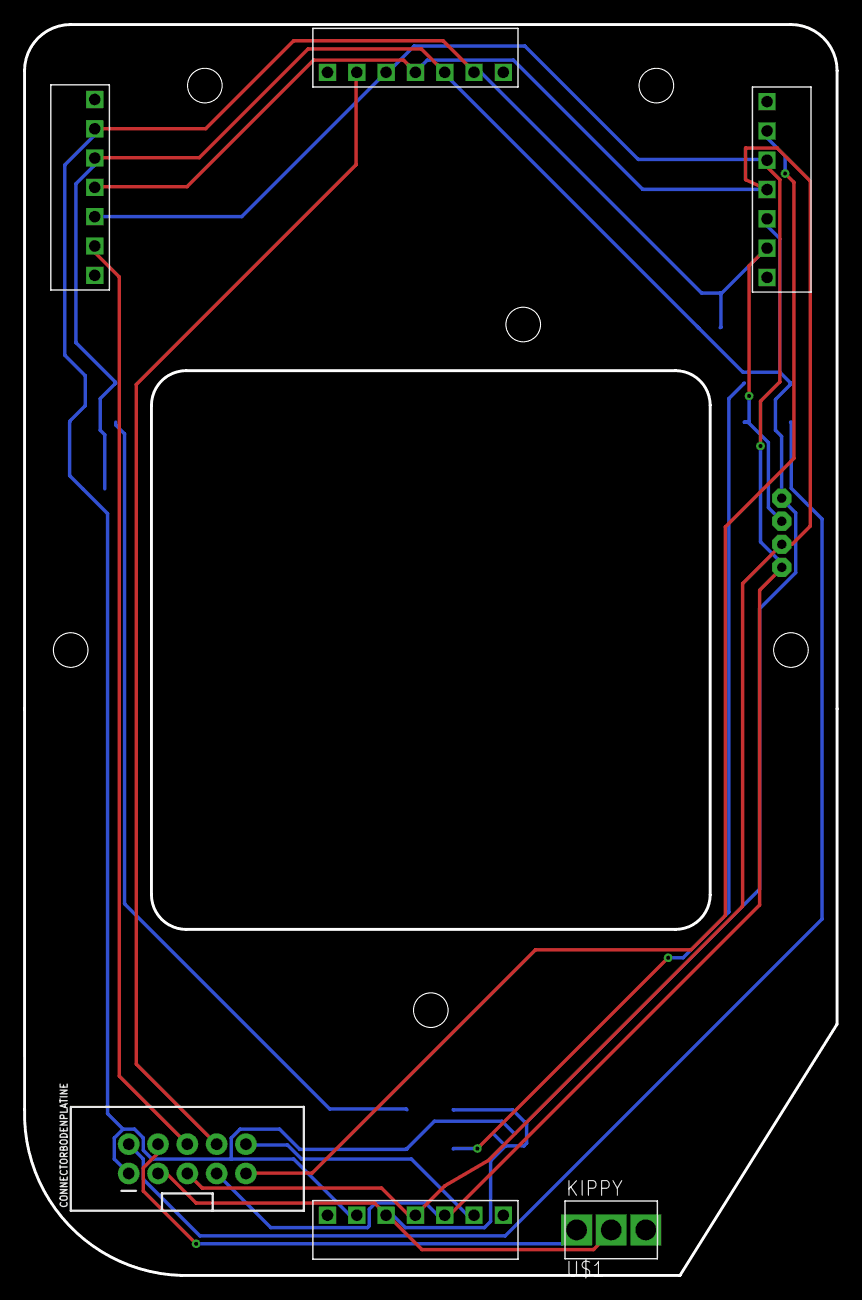
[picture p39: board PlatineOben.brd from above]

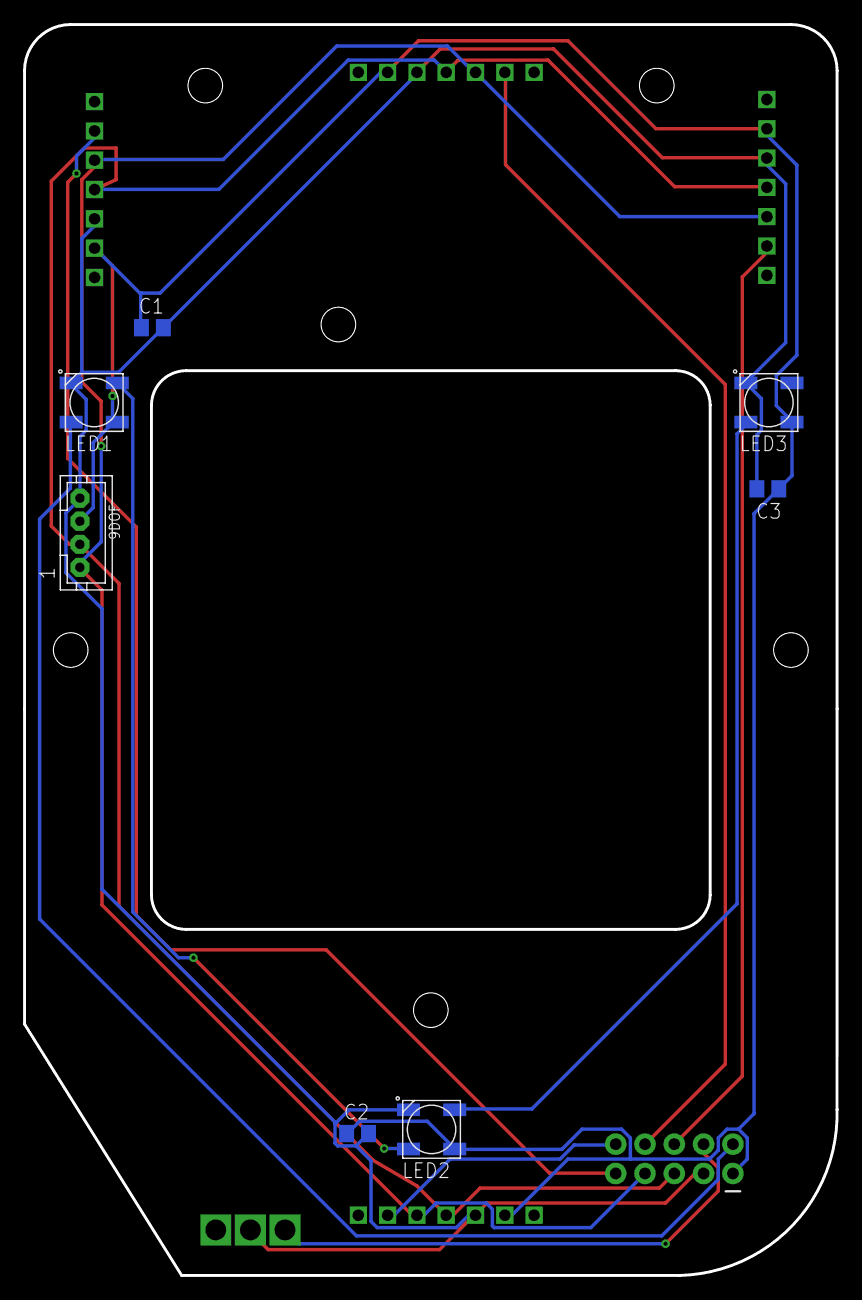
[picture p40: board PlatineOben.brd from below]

Board: 2 copper layers, 70.4 x 108.4 mm, 13 parts (7 on the bottom side), 12 nets.

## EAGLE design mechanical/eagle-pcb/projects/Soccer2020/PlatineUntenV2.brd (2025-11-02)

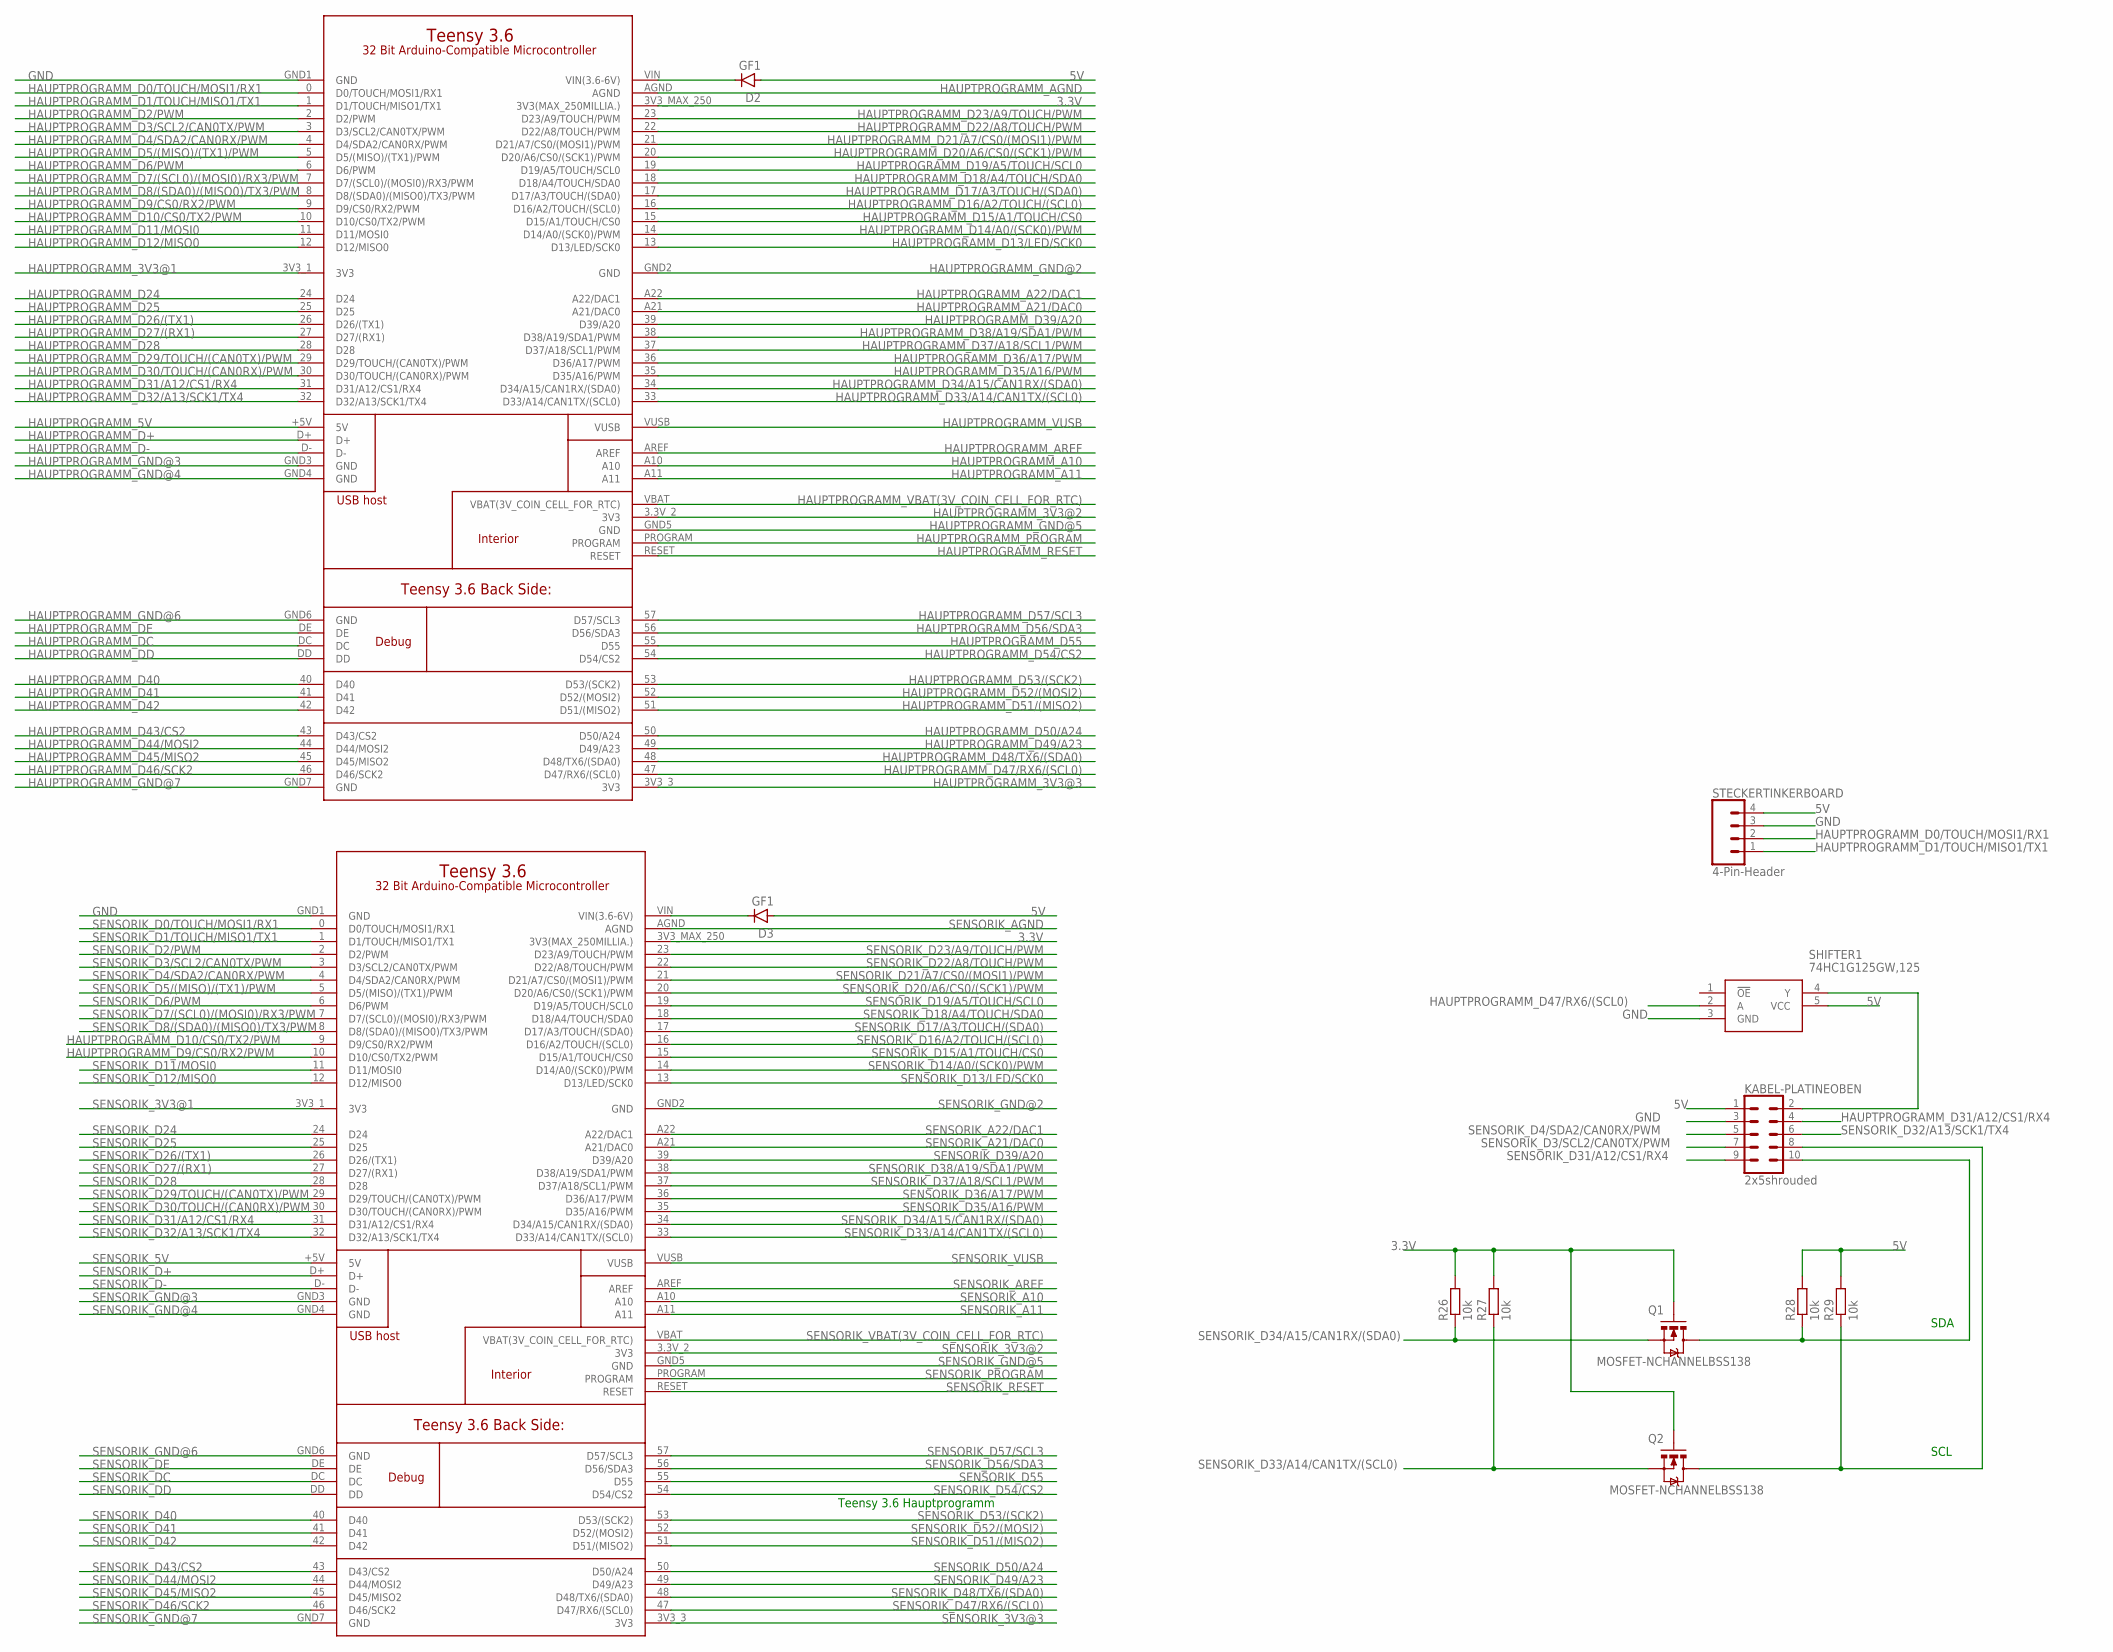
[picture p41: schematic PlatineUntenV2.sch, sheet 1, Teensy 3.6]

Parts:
D2, D3: GF1; SMA-DO214AC
HAUPTPROGRAMM: TEENSY3.6_FULL
KABEL-PLATINEOBEN: 2x5shrouded; 2X5-SHROUDED(3D)
Q1, Q2: MOSFET-NCHANNELBSS138; SOT23
R26, R27, R28, R29: 10k; R0805
SENSORIK: TEENSY3.6_FULL
SHIFTER1: 74HC1G125GW,125; SOT65P212X110-5N
STECKERTINKERBOARD: 4-Pin-Header; 1X04

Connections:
3.3V: HAUPTPROGRAMM.3V3_MAX_250 (3V3(MAX_250MILLIA.)), Q1.1 (G), Q2.1 (G), R26.2, R27.2, SENSORIK.3V3_MAX_250 (3V3(MAX_250MILLIA.)); also elsewhere on the board
5V: D2.A, D3.A, KABEL-PLATINEOBEN.1, R28.2, R29.2, SHIFTER1.5 (VCC), STECKERTINKERBOARD.4; also elsewhere on the board
GND: HAUPTPROGRAMM.GND1 (GND), KABEL-PLATINEOBEN.3, SENSORIK.GND1 (GND), SHIFTER1.3 (GND), STECKERTINKERBOARD.3; also elsewhere on the board
HAUPTPROGRAMM_3V3@1: HAUPTPROGRAMM.3V3_1 (3V3)
HAUPTPROGRAMM_3V3@2: HAUPTPROGRAMM.3.3V_2 (3V3)
HAUPTPROGRAMM_3V3@3: HAUPTPROGRAMM.3V3_3 (3V3)
HAUPTPROGRAMM_5V: HAUPTPROGRAMM.+5V (5V)
HAUPTPROGRAMM_A10: HAUPTPROGRAMM.A10
HAUPTPROGRAMM_A11: HAUPTPROGRAMM.A11
HAUPTPROGRAMM_A21/DAC0: HAUPTPROGRAMM.A21 (A21/DAC0)
HAUPTPROGRAMM_A22/DAC1: HAUPTPROGRAMM.A22 (A22/DAC1)
HAUPTPROGRAMM_AGND: HAUPTPROGRAMM.AGND
HAUPTPROGRAMM_AREF: HAUPTPROGRAMM.AREF
HAUPTPROGRAMM_D0/TOUCH/MOSI1/RX1: HAUPTPROGRAMM.0 (D0/TOUCH/MOSI1/RX1), STECKERTINKERBOARD.2
HAUPTPROGRAMM_D1/TOUCH/MISO1/TX1: HAUPTPROGRAMM.1 (D1/TOUCH/MISO1/TX1), STECKERTINKERBOARD.1
HAUPTPROGRAMM_D2/PWM: HAUPTPROGRAMM.2 (D2/PWM); also elsewhere on the board
HAUPTPROGRAMM_D3/SCL2/CAN0TX/PWM: HAUPTPROGRAMM.3 (D3/SCL2/CAN0TX/PWM)
HAUPTPROGRAMM_D4/SDA2/CAN0RX/PWM: HAUPTPROGRAMM.4 (D4/SDA2/CAN0RX/PWM); also elsewhere on the board
HAUPTPROGRAMM_D5/(MISO)/(TX1)/PWM: HAUPTPROGRAMM.5 (D5/(MISO)/(TX1)/PWM)
HAUPTPROGRAMM_D6/PWM: HAUPTPROGRAMM.6 (D6/PWM); also elsewhere on the board
HAUPTPROGRAMM_D7/(SCL0)/(MOSI0)/RX3/PWM: HAUPTPROGRAMM.7 (D7/(SCL0)/(MOSI0)/RX3/PWM); also elsewhere on the board
HAUPTPROGRAMM_D8/(SDA0)/(MISO0)/TX3/PWM: HAUPTPROGRAMM.8 (D8/(SDA0)/(MISO0)/TX3/PWM)
HAUPTPROGRAMM_D9/CS0/RX2/PWM: HAUPTPROGRAMM.9 (D9/CS0/RX2/PWM), SENSORIK.10 (D10/CS0/TX2/PWM)
HAUPTPROGRAMM_D10/CS0/TX2/PWM: HAUPTPROGRAMM.10 (D10/CS0/TX2/PWM), SENSORIK.9 (D9/CS0/RX2/PWM)
HAUPTPROGRAMM_D11/MOSI0: HAUPTPROGRAMM.11 (D11/MOSI0); also elsewhere on the board
HAUPTPROGRAMM_D12/MISO0: HAUPTPROGRAMM.12 (D12/MISO0)
HAUPTPROGRAMM_D13/LED/SCK0: HAUPTPROGRAMM.13 (D13/LED/SCK0); also elsewhere on the board
HAUPTPROGRAMM_D14/A0/(SCK0)/PWM: HAUPTPROGRAMM.14 (D14/A0/(SCK0)/PWM); also elsewhere on the board
HAUPTPROGRAMM_D15/A1/TOUCH/CS0: HAUPTPROGRAMM.15 (D15/A1/TOUCH/CS0); also elsewhere on the board
HAUPTPROGRAMM_D16/A2/TOUCH/(SCL0): HAUPTPROGRAMM.16 (D16/A2/TOUCH/(SCL0)); also elsewhere on the board
HAUPTPROGRAMM_D17/A3/TOUCH/(SDA0): HAUPTPROGRAMM.17 (D17/A3/TOUCH/(SDA0)); also elsewhere on the board
HAUPTPROGRAMM_D18/A4/TOUCH/SDA0: HAUPTPROGRAMM.18 (D18/A4/TOUCH/SDA0); also elsewhere on the board
HAUPTPROGRAMM_D19/A5/TOUCH/SCL0: HAUPTPROGRAMM.19 (D19/A5/TOUCH/SCL0); also elsewhere on the board
HAUPTPROGRAMM_D20/A6/CS0/(SCK1)/PWM: HAUPTPROGRAMM.20 (D20/A6/CS0/(SCK1)/PWM); also elsewhere on the board
HAUPTPROGRAMM_D21/A7/CS0/(MOSI1)/PWM: HAUPTPROGRAMM.21 (D21/A7/CS0/(MOSI1)/PWM); also elsewhere on the board
HAUPTPROGRAMM_D22/A8/TOUCH/PWM: HAUPTPROGRAMM.22 (D22/A8/TOUCH/PWM); also elsewhere on the board
HAUPTPROGRAMM_D23/A9/TOUCH/PWM: HAUPTPROGRAMM.23 (D23/A9/TOUCH/PWM); also elsewhere on the board
HAUPTPROGRAMM_D24: HAUPTPROGRAMM.24 (D24); also elsewhere on the board
HAUPTPROGRAMM_D25: HAUPTPROGRAMM.25 (D25); also elsewhere on the board
HAUPTPROGRAMM_D26/(TX1): HAUPTPROGRAMM.26 (D26/(TX1)); also elsewhere on the board
HAUPTPROGRAMM_D27/(RX1): HAUPTPROGRAMM.27 (D27/(RX1))
HAUPTPROGRAMM_D28: HAUPTPROGRAMM.28 (D28); also elsewhere on the board
HAUPTPROGRAMM_D29/TOUCH/(CAN0TX)/PWM: HAUPTPROGRAMM.29 (D29/TOUCH/(CAN0TX)/PWM); also elsewhere on the board
HAUPTPROGRAMM_D30/TOUCH/(CAN0RX)/PWM: HAUPTPROGRAMM.30 (D30/TOUCH/(CAN0RX)/PWM)
HAUPTPROGRAMM_D31/A12/CS1/RX4: HAUPTPROGRAMM.31 (D31/A12/CS1/RX4), KABEL-PLATINEOBEN.4
HAUPTPROGRAMM_D32/A13/SCK1/TX4: HAUPTPROGRAMM.32 (D32/A13/SCK1/TX4); also elsewhere on the board
HAUPTPROGRAMM_D33/A14/CAN1TX/(SCL0): HAUPTPROGRAMM.33 (D33/A14/CAN1TX/(SCL0)); also elsewhere on the board
HAUPTPROGRAMM_D34/A15/CAN1RX/(SDA0): HAUPTPROGRAMM.34 (D34/A15/CAN1RX/(SDA0)); also elsewhere on the board
HAUPTPROGRAMM_D35/A16/PWM: HAUPTPROGRAMM.35 (D35/A16/PWM); also elsewhere on the board
HAUPTPROGRAMM_D36/A17/PWM: HAUPTPROGRAMM.36 (D36/A17/PWM); also elsewhere on the board
HAUPTPROGRAMM_D37/A18/SCL1/PWM: HAUPTPROGRAMM.37 (D37/A18/SCL1/PWM); also elsewhere on the board
HAUPTPROGRAMM_D38/A19/SDA1/PWM: HAUPTPROGRAMM.38 (D38/A19/SDA1/PWM); also elsewhere on the board
HAUPTPROGRAMM_D39/A20: HAUPTPROGRAMM.39 (D39/A20); also elsewhere on the board
HAUPTPROGRAMM_D40: HAUPTPROGRAMM.40 (D40); also elsewhere on the board
HAUPTPROGRAMM_D41: HAUPTPROGRAMM.41 (D41); also elsewhere on the board
HAUPTPROGRAMM_D42: HAUPTPROGRAMM.42 (D42); also elsewhere on the board
HAUPTPROGRAMM_D43/CS2: HAUPTPROGRAMM.43 (D43/CS2); also elsewhere on the board
HAUPTPROGRAMM_D44/MOSI2: HAUPTPROGRAMM.44 (D44/MOSI2); also elsewhere on the board
HAUPTPROGRAMM_D45/MISO2: HAUPTPROGRAMM.45 (D45/MISO2); also elsewhere on the board
HAUPTPROGRAMM_D46/SCK2: HAUPTPROGRAMM.46 (D46/SCK2); also elsewhere on the board
HAUPTPROGRAMM_D47/RX6/(SCL0): HAUPTPROGRAMM.47 (D47/RX6/(SCL0)), SHIFTER1.2 (A)
HAUPTPROGRAMM_D48/TX6/(SDA0): HAUPTPROGRAMM.48 (D48/TX6/(SDA0)); also elsewhere on the board
HAUPTPROGRAMM_D49/A23: HAUPTPROGRAMM.49 (D49/A23); also elsewhere on the board
HAUPTPROGRAMM_D50/A24: HAUPTPROGRAMM.50 (D50/A24)
HAUPTPROGRAMM_D51/(MISO2): HAUPTPROGRAMM.51 (D51/(MISO2)); also elsewhere on the board
HAUPTPROGRAMM_D52/(MOSI2): HAUPTPROGRAMM.52 (D52/(MOSI2))
HAUPTPROGRAMM_D53/(SCK2): HAUPTPROGRAMM.53 (D53/(SCK2)); also elsewhere on the board
HAUPTPROGRAMM_D54/CS2: HAUPTPROGRAMM.54 (D54/CS2); also elsewhere on the board
HAUPTPROGRAMM_D55: HAUPTPROGRAMM.55 (D55); also elsewhere on the board
HAUPTPROGRAMM_D56/SDA3: HAUPTPROGRAMM.56 (D56/SDA3)
HAUPTPROGRAMM_D57/SCL3: HAUPTPROGRAMM.57 (D57/SCL3)
HAUPTPROGRAMM_D+: HAUPTPROGRAMM.D+
HAUPTPROGRAMM_D-: HAUPTPROGRAMM.D-
HAUPTPROGRAMM_DC: HAUPTPROGRAMM.DC
HAUPTPROGRAMM_DD: HAUPTPROGRAMM.DD
HAUPTPROGRAMM_DE: HAUPTPROGRAMM.DE
HAUPTPROGRAMM_GND@2: HAUPTPROGRAMM.GND2 (GND)
HAUPTPROGRAMM_GND@3: HAUPTPROGRAMM.GND3 (GND)
HAUPTPROGRAMM_GND@4: HAUPTPROGRAMM.GND4 (GND)
HAUPTPROGRAMM_GND@5: HAUPTPROGRAMM.GND5 (GND)
HAUPTPROGRAMM_GND@6: HAUPTPROGRAMM.GND6 (GND)
HAUPTPROGRAMM_GND@7: HAUPTPROGRAMM.GND7 (GND)
HAUPTPROGRAMM_PROGRAM: HAUPTPROGRAMM.PROGRAM
HAUPTPROGRAMM_RESET: HAUPTPROGRAMM.RESET
HAUPTPROGRAMM_VBAT(3V_COIN_CELL_FOR_RTC): HAUPTPROGRAMM.VBAT (VBAT(3V_COIN_CELL_FOR_RTC))
HAUPTPROGRAMM_VUSB: HAUPTPROGRAMM.VUSB
unnamed: D2.K (C), HAUPTPROGRAMM.VIN (VIN(3.6-6V))
unnamed: D3.K (C), SENSORIK.VIN (VIN(3.6-6V))
unnamed: KABEL-PLATINEOBEN.10, Q1.3 (D), R28.1
unnamed: KABEL-PLATINEOBEN.8, Q2.3 (D), R29.1
unnamed: KABEL-PLATINEOBEN.2, SHIFTER1.4 (Y)
SENSORIK_3V3@1: SENSORIK.3V3_1 (3V3)
SENSORIK_3V3@2: SENSORIK.3.3V_2 (3V3)
SENSORIK_3V3@3: SENSORIK.3V3_3 (3V3)
SENSORIK_5V: SENSORIK.+5V (5V)
SENSORIK_A10: SENSORIK.A10
SENSORIK_A11: SENSORIK.A11
SENSORIK_A21/DAC0: SENSORIK.A21 (A21/DAC0)
SENSORIK_A22/DAC1: SENSORIK.A22 (A22/DAC1)
SENSORIK_AGND: SENSORIK.AGND
SENSORIK_AREF: SENSORIK.AREF
SENSORIK_D0/TOUCH/MOSI1/RX1: SENSORIK.0 (D0/TOUCH/MOSI1/RX1)
SENSORIK_D1/TOUCH/MISO1/TX1: SENSORIK.1 (D1/TOUCH/MISO1/TX1)
SENSORIK_D2/PWM: SENSORIK.2 (D2/PWM)
SENSORIK_D3/SCL2/CAN0TX/PWM: KABEL-PLATINEOBEN.7, SENSORIK.3 (D3/SCL2/CAN0TX/PWM); also elsewhere on the board
SENSORIK_D4/SDA2/CAN0RX/PWM: KABEL-PLATINEOBEN.5, SENSORIK.4 (D4/SDA2/CAN0RX/PWM); also elsewhere on the board
SENSORIK_D5/(MISO)/(TX1)/PWM: SENSORIK.5 (D5/(MISO)/(TX1)/PWM)
SENSORIK_D6/PWM: SENSORIK.6 (D6/PWM)
SENSORIK_D7/(SCL0)/(MOSI0)/RX3/PWM: SENSORIK.7 (D7/(SCL0)/(MOSI0)/RX3/PWM)
SENSORIK_D8/(SDA0)/(MISO0)/TX3/PWM: SENSORIK.8 (D8/(SDA0)/(MISO0)/TX3/PWM)
SENSORIK_D11/MOSI0: SENSORIK.11 (D11/MOSI0)
SENSORIK_D12/MISO0: SENSORIK.12 (D12/MISO0)
SENSORIK_D13/LED/SCK0: SENSORIK.13 (D13/LED/SCK0)
SENSORIK_D14/A0/(SCK0)/PWM: SENSORIK.14 (D14/A0/(SCK0)/PWM)
SENSORIK_D15/A1/TOUCH/CS0: SENSORIK.15 (D15/A1/TOUCH/CS0)
SENSORIK_D16/A2/TOUCH/(SCL0): SENSORIK.16 (D16/A2/TOUCH/(SCL0))
SENSORIK_D17/A3/TOUCH/(SDA0): SENSORIK.17 (D17/A3/TOUCH/(SDA0))
SENSORIK_D18/A4/TOUCH/SDA0: SENSORIK.18 (D18/A4/TOUCH/SDA0); also elsewhere on the board
SENSORIK_D19/A5/TOUCH/SCL0: SENSORIK.19 (D19/A5/TOUCH/SCL0); also elsewhere on the board
SENSORIK_D20/A6/CS0/(SCK1)/PWM: SENSORIK.20 (D20/A6/CS0/(SCK1)/PWM)
SENSORIK_D21/A7/CS0/(MOSI1)/PWM: SENSORIK.21 (D21/A7/CS0/(MOSI1)/PWM)
SENSORIK_D22/A8/TOUCH/PWM: SENSORIK.22 (D22/A8/TOUCH/PWM)
SENSORIK_D23/A9/TOUCH/PWM: SENSORIK.23 (D23/A9/TOUCH/PWM)
SENSORIK_D24: SENSORIK.24 (D24); also elsewhere on the board
SENSORIK_D25: SENSORIK.25 (D25); also elsewhere on the board
SENSORIK_D26/(TX1): SENSORIK.26 (D26/(TX1))
SENSORIK_D27/(RX1): SENSORIK.27 (D27/(RX1))
SENSORIK_D28: SENSORIK.28 (D28); also elsewhere on the board
SENSORIK_D29/TOUCH/(CAN0TX)/PWM: SENSORIK.29 (D29/TOUCH/(CAN0TX)/PWM)
SENSORIK_D30/TOUCH/(CAN0RX)/PWM: SENSORIK.30 (D30/TOUCH/(CAN0RX)/PWM)
SENSORIK_D31/A12/CS1/RX4: KABEL-PLATINEOBEN.9, SENSORIK.31 (D31/A12/CS1/RX4)
SENSORIK_D32/A13/SCK1/TX4: KABEL-PLATINEOBEN.6, SENSORIK.32 (D32/A13/SCK1/TX4)
SENSORIK_D33/A14/CAN1TX/(SCL0): Q2.2 (S), R27.1, SENSORIK.33 (D33/A14/CAN1TX/(SCL0))
SENSORIK_D34/A15/CAN1RX/(SDA0): Q1.2 (S), R26.1, SENSORIK.34 (D34/A15/CAN1RX/(SDA0))
SENSORIK_D35/A16/PWM: SENSORIK.35 (D35/A16/PWM)
SENSORIK_D36/A17/PWM: SENSORIK.36 (D36/A17/PWM)
SENSORIK_D37/A18/SCL1/PWM: SENSORIK.37 (D37/A18/SCL1/PWM); also elsewhere on the board
SENSORIK_D38/A19/SDA1/PWM: SENSORIK.38 (D38/A19/SDA1/PWM); also elsewhere on the board
SENSORIK_D39/A20: SENSORIK.39 (D39/A20)
SENSORIK_D40: SENSORIK.40 (D40); also elsewhere on the board
SENSORIK_D41: SENSORIK.41 (D41); also elsewhere on the board
SENSORIK_D42: SENSORIK.42 (D42); also elsewhere on the board
SENSORIK_D43/CS2: SENSORIK.43 (D43/CS2); also elsewhere on the board
SENSORIK_D44/MOSI2: SENSORIK.44 (D44/MOSI2)
SENSORIK_D45/MISO2: SENSORIK.45 (D45/MISO2)
SENSORIK_D46/SCK2: SENSORIK.46 (D46/SCK2); also elsewhere on the board
SENSORIK_D47/RX6/(SCL0): SENSORIK.47 (D47/RX6/(SCL0))
SENSORIK_D48/TX6/(SDA0): SENSORIK.48 (D48/TX6/(SDA0))
SENSORIK_D49/A23: SENSORIK.49 (D49/A23)
SENSORIK_D50/A24: SENSORIK.50 (D50/A24)
SENSORIK_D51/(MISO2): SENSORIK.51 (D51/(MISO2))
SENSORIK_D52/(MOSI2): SENSORIK.52 (D52/(MOSI2))
SENSORIK_D53/(SCK2): SENSORIK.53 (D53/(SCK2))
SENSORIK_D54/CS2: SENSORIK.54 (D54/CS2)
SENSORIK_D55: SENSORIK.55 (D55)
SENSORIK_D56/SDA3: SENSORIK.56 (D56/SDA3); also elsewhere on the board
SENSORIK_D57/SCL3: SENSORIK.57 (D57/SCL3); also elsewhere on the board
SENSORIK_D+: SENSORIK.D+
SENSORIK_D-: SENSORIK.D-
SENSORIK_DC: SENSORIK.DC
SENSORIK_DD: SENSORIK.DD
SENSORIK_DE: SENSORIK.DE
SENSORIK_GND@2: SENSORIK.GND2 (GND)
SENSORIK_GND@3: SENSORIK.GND3 (GND)
SENSORIK_GND@4: SENSORIK.GND4 (GND)
SENSORIK_GND@5: SENSORIK.GND5 (GND)
SENSORIK_GND@6: SENSORIK.GND6 (GND)
SENSORIK_GND@7: SENSORIK.GND7 (GND)
SENSORIK_PROGRAM: SENSORIK.PROGRAM
SENSORIK_RESET: SENSORIK.RESET
SENSORIK_VBAT(3V_COIN_CELL_FOR_RTC): SENSORIK.VBAT (VBAT(3V_COIN_CELL_FOR_RTC))
SENSORIK_VUSB: SENSORIK.VUSB

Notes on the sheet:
Teensy 3.6 Hauptprogramm
SDA
SCL

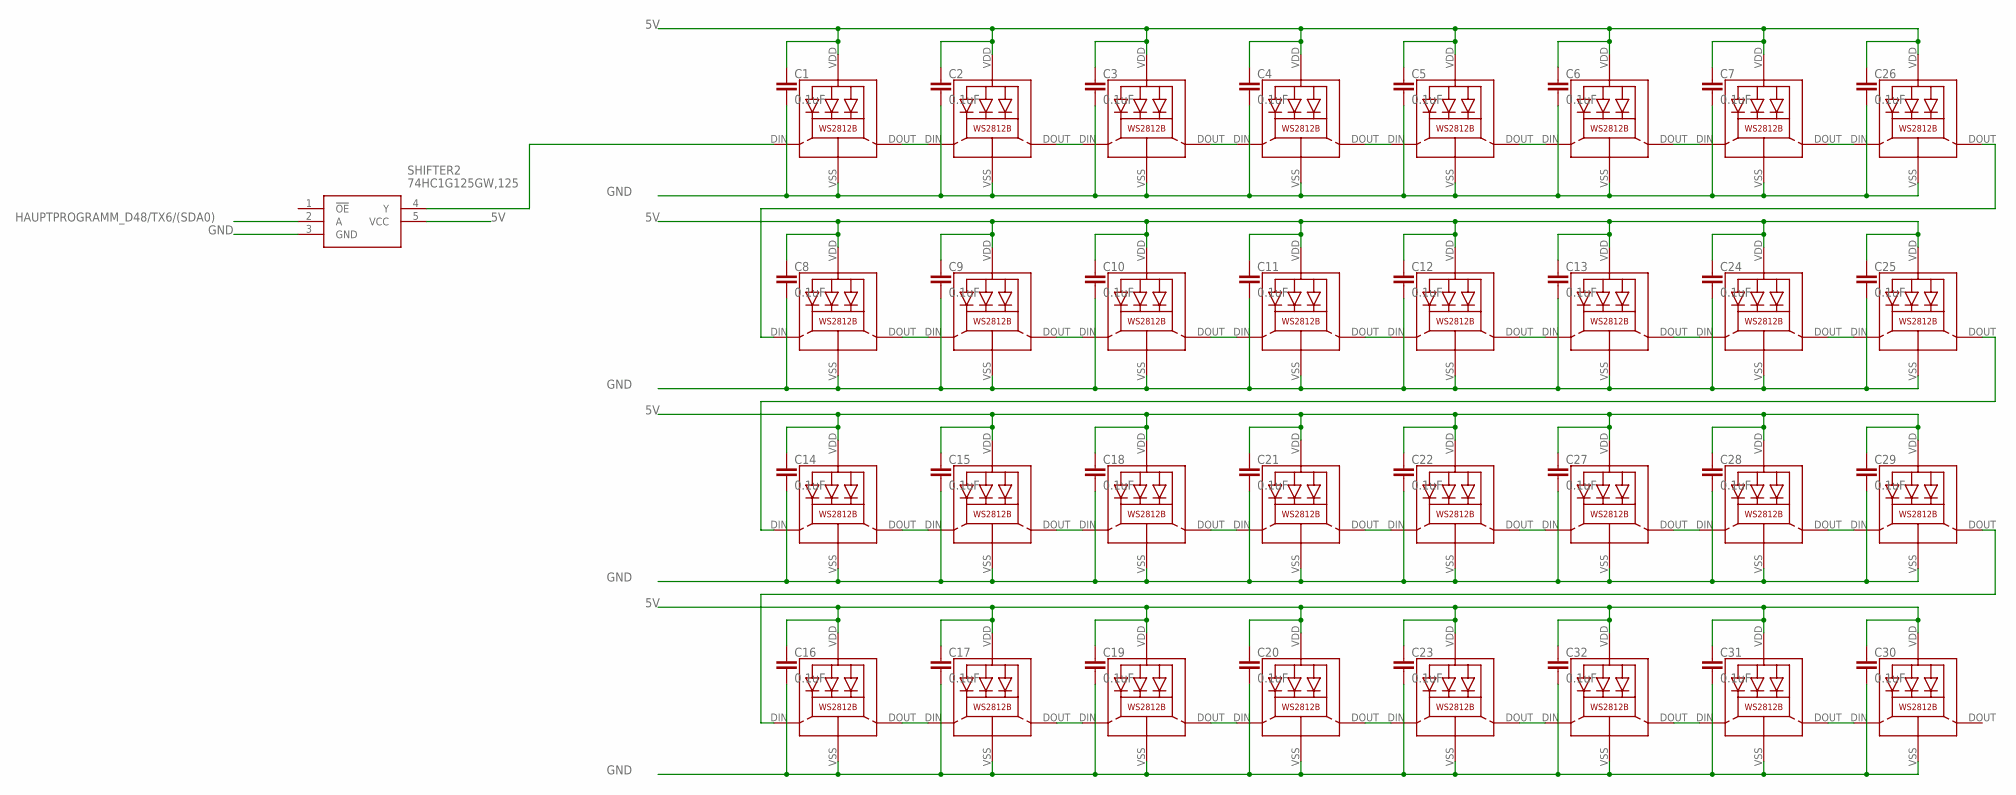
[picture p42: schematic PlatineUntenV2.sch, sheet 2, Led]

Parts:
C1, C2, C3, C4, C5, C6, C7, C8, C9, C10, C11, C12, C13, C14, C15, C16, C17, C18, C19, C20, C21, C22, C23, C24, C25, C26, C27, C28, C29, C30, C31, C32: 0.1uF; C0805
LED33, LED34, LED35, LED36, LED37, LED38, LED39, LED40, LED41, LED42, LED43, LED44, LED45, LED46, LED47, LED48, LED49, LED50, LED51, LED52, LED53, LED54, LED55, LED56, LED57, LED58, LED59, LED60, LED61, LED62, LED63, LED64: WS2812B
SHIFTER2: 74HC1G125GW,125; SOT65P212X110-5N

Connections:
5V: C1.1, C2.1, C3.1, C4.1, C5.1, C6.1, C7.1, C8.1, C9.1, C10.1, C11.1, C12.1, C13.1, C14.1, C15.1, C16.1, C17.1, C18.1, C19.1, C20.1, C21.1, C22.1, C23.1, C24.1, C25.1, C26.1, C27.1, C28.1, C29.1, C30.1, C31.1, C32.1, LED33.VDD, LED34.VDD, LED35.VDD, LED36.VDD, LED37.VDD, LED38.VDD, LED39.VDD, LED40.VDD, LED41.VDD, LED42.VDD, LED43.VDD, LED44.VDD, LED45.VDD, LED46.VDD, LED47.VDD, LED48.VDD, LED49.VDD, LED50.VDD, LED51.VDD, LED52.VDD, LED53.VDD, LED54.VDD, LED55.VDD, LED56.VDD, LED57.VDD, LED58.VDD, LED59.VDD, LED60.VDD, LED61.VDD, LED62.VDD, LED63.VDD, LED64.VDD, SHIFTER2.5 (VCC); also elsewhere on the board
GND: C1.2, C2.2, C3.2, C4.2, C5.2, C6.2, C7.2, C8.2, C9.2, C10.2, C11.2, C12.2, C13.2, C14.2, C15.2, C16.2, C17.2, C18.2, C19.2, C20.2, C21.2, C22.2, C23.2, C24.2, C25.2, C26.2, C27.2, C28.2, C29.2, C30.2, C31.2, C32.2, LED33.VSS (GND), LED34.VSS (GND), LED35.VSS (GND), LED36.VSS (GND), LED37.VSS (GND), LED38.VSS (GND), LED39.VSS (GND), LED40.VSS (GND), LED41.VSS (GND), LED42.VSS (GND), LED43.VSS (GND), LED44.VSS (GND), LED45.VSS (GND), LED46.VSS (GND), LED47.VSS (GND), LED48.VSS (GND), LED49.VSS (GND), LED50.VSS (GND), LED51.VSS (GND), LED52.VSS (GND), LED53.VSS (GND), LED54.VSS (GND), LED55.VSS (GND), LED56.VSS (GND), LED57.VSS (GND), LED58.VSS (GND), LED59.VSS (GND), LED60.VSS (GND), LED61.VSS (GND), LED62.VSS (GND), LED63.VSS (GND), LED64.VSS (GND), SHIFTER2.3 (GND); also elsewhere on the board
HAUPTPROGRAMM_D48/TX6/(SDA0): SHIFTER2.2 (A); also elsewhere on the board
unnamed: LED33.DIN (DI), SHIFTER2.4 (Y)
unnamed: LED33.DOUT (DO), LED34.DIN (DI)
unnamed: LED34.DOUT (DO), LED35.DIN (DI)
unnamed: LED35.DOUT (DO), LED36.DIN (DI)
unnamed: LED36.DOUT (DO), LED37.DIN (DI)
unnamed: LED37.DOUT (DO), LED38.DIN (DI)
unnamed: LED38.DOUT (DO), LED39.DIN (DI)
unnamed: LED39.DOUT (DO), LED40.DIN (DI)
unnamed: LED40.DOUT (DO), LED41.DIN (DI)
unnamed: LED41.DOUT (DO), LED42.DIN (DI)
unnamed: LED42.DOUT (DO), LED43.DIN (DI)
unnamed: LED43.DOUT (DO), LED44.DIN (DI)
unnamed: LED44.DOUT (DO), LED45.DIN (DI)
unnamed: LED45.DOUT (DO), LED46.DIN (DI)
unnamed: LED46.DOUT (DO), LED47.DIN (DI)
unnamed: LED47.DOUT (DO), LED48.DIN (DI)
unnamed: LED48.DOUT (DO), LED49.DIN (DI)
unnamed: LED49.DOUT (DO), LED50.DIN (DI)
unnamed: LED50.DOUT (DO), LED51.DIN (DI)
unnamed: LED51.DOUT (DO), LED52.DIN (DI)
unnamed: LED52.DOUT (DO), LED53.DIN (DI)
unnamed: LED53.DOUT (DO), LED54.DIN (DI)
unnamed: LED54.DOUT (DO), LED55.DIN (DI)
unnamed: LED55.DOUT (DO), LED56.DIN (DI)
unnamed: LED56.DOUT (DO), LED57.DIN (DI)
unnamed: LED57.DOUT (DO), LED58.DIN (DI)
unnamed: LED58.DOUT (DO), LED59.DIN (DI)
unnamed: LED59.DOUT (DO), LED60.DIN (DI)
unnamed: LED60.DOUT (DO), LED61.DIN (DI)
unnamed: LED61.DOUT (DO), LED62.DIN (DI)
unnamed: LED62.DOUT (DO), LED63.DIN (DI)
unnamed: LED63.DOUT (DO), LED64.DIN (DI)

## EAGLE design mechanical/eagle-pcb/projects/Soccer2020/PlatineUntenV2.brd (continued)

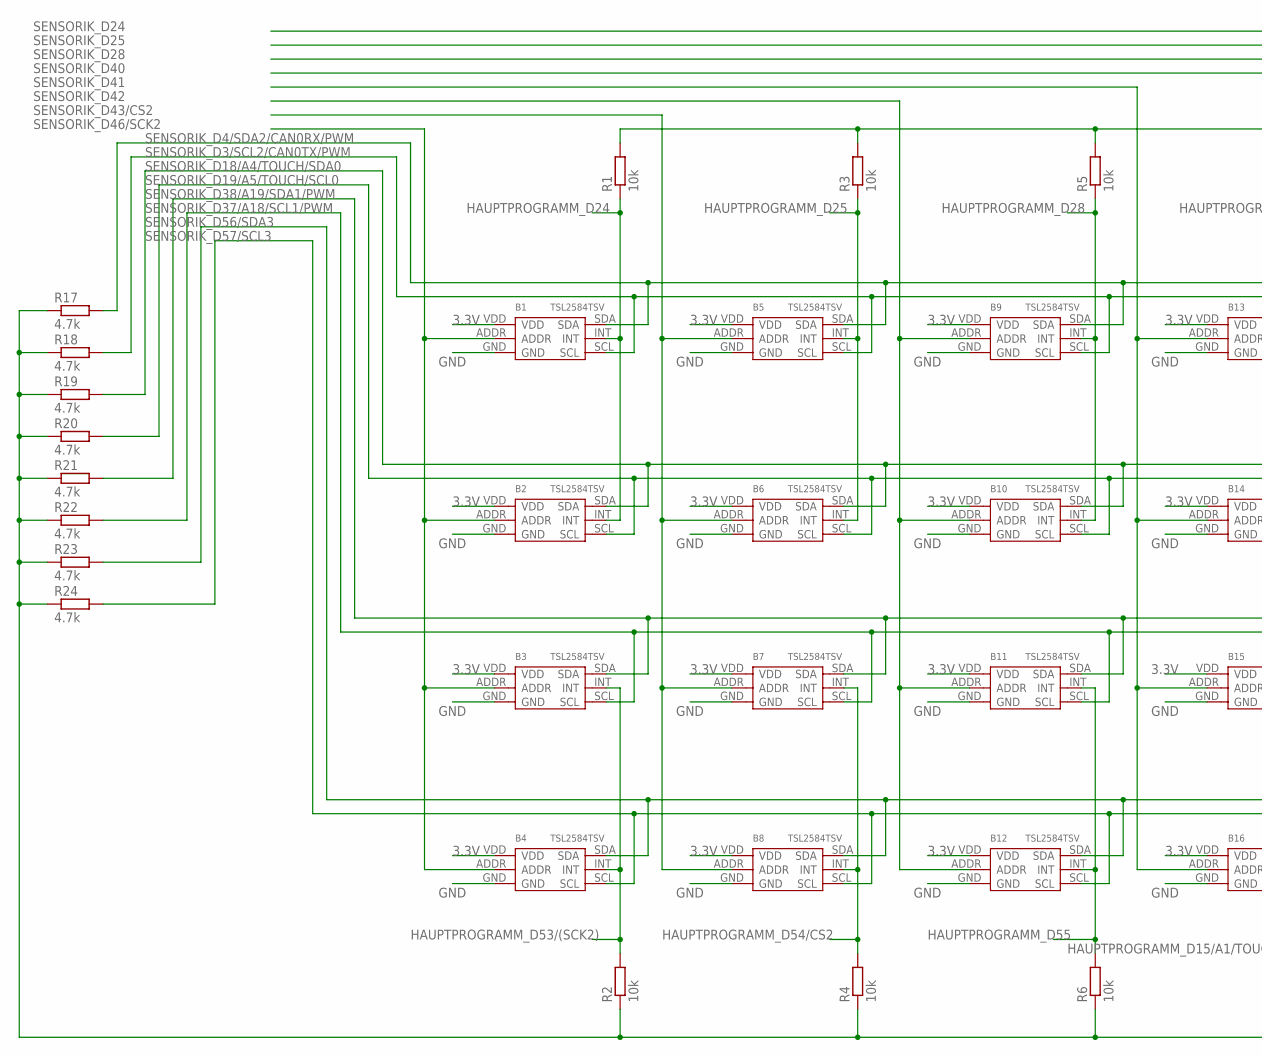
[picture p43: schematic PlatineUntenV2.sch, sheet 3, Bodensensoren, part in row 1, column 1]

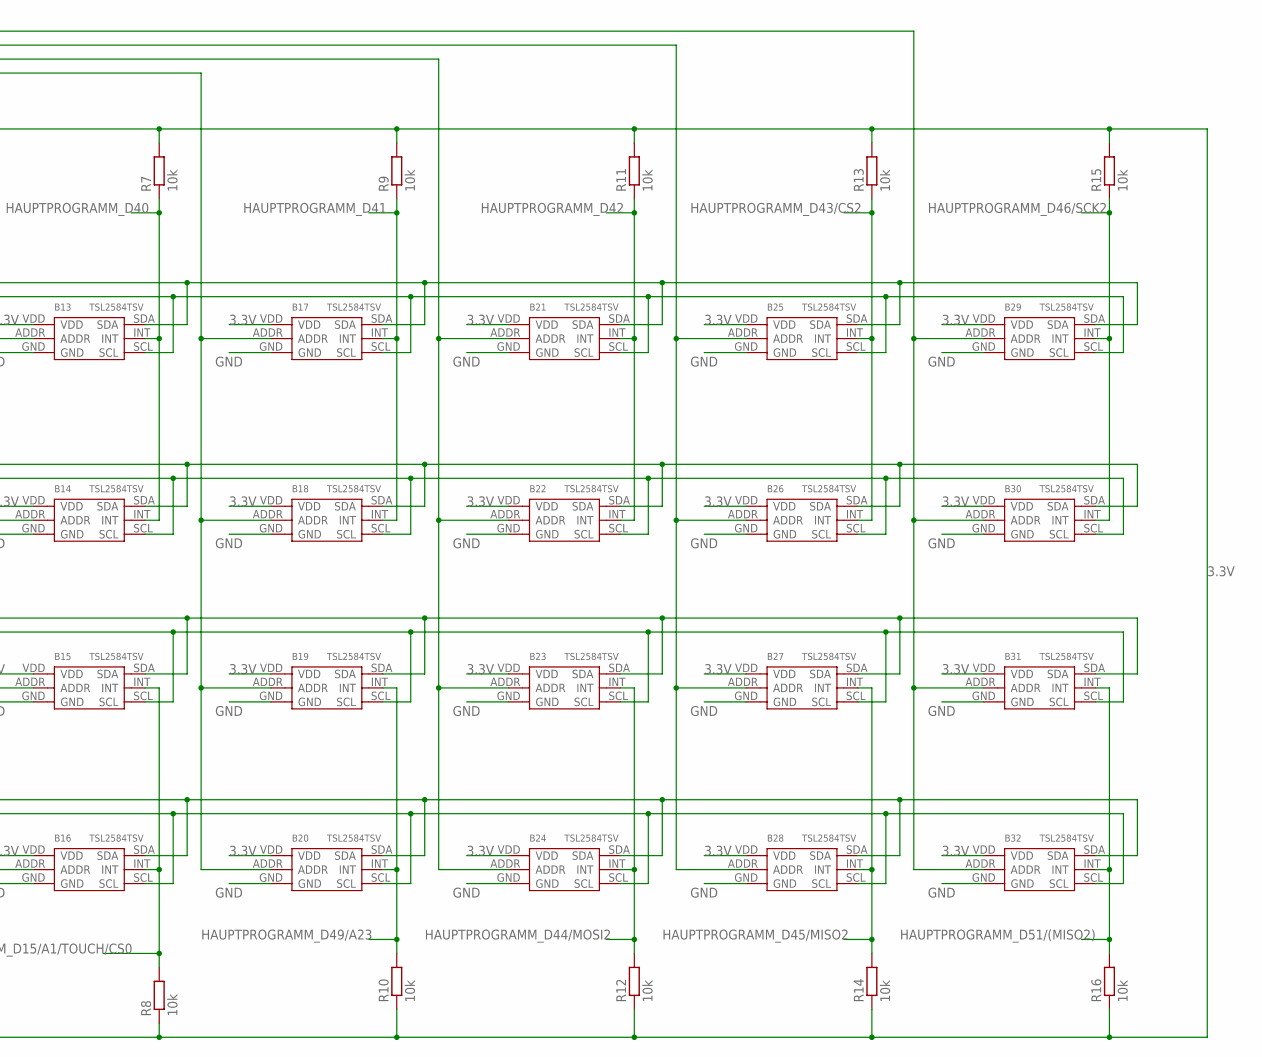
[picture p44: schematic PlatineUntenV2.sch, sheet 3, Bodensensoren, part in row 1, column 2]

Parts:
B1, B2, B3, B4, B5, B6, B7, B8, B9, B10, B11, B12, B13, B14, B15, B16, B17, B18, B19, B20, B21, B22, B23, B24, B25, B26, B27, B28, B29, B30, B31, B32: TSL2584TSV
R1, R2, R3, R4, R5, R6, R7, R8, R9, R10, R11, R12, R13, R14, R15, R16: 10k; R0805
R17, R18, R19, R20, R21, R22, R23, R24: 4.7k; R0805

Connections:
3.3V: B1.VDD, B2.VDD, B3.VDD, B4.VDD, B5.VDD, B6.VDD, B7.VDD, B8.VDD, B9.VDD, B10.VDD, B11.VDD, B12.VDD, B13.VDD, B14.VDD, B15.VDD, B16.VDD, B17.VDD, B18.VDD, B19.VDD, B20.VDD, B21.VDD, B22.VDD, B23.VDD, B24.VDD, B25.VDD, B26.VDD, B27.VDD, B28.VDD, B29.VDD, B30.VDD, B31.VDD, B32.VDD, R1.2, R2.1, R3.2, R4.1, R5.2, R6.1, R7.2, R8.1, R9.2, R10.1, R11.2, R12.1, R13.2, R14.1, R15.2, R16.1, R17.1, R18.1, R19.1, R20.1, R21.1, R22.1, R23.1, R24.1; also elsewhere on the board
GND: B1.GND, B2.GND, B3.GND, B4.GND, B5.GND, B6.GND, B7.GND, B8.GND, B9.GND, B10.GND, B11.GND, B12.GND, B13.GND, B14.GND, B15.GND, B16.GND, B17.GND, B18.GND, B19.GND, B20.GND, B21.GND, B22.GND, B23.GND, B24.GND, B25.GND, B26.GND, B27.GND, B28.GND, B29.GND, B30.GND, B31.GND, B32.GND; also elsewhere on the board
HAUPTPROGRAMM_D15/A1/TOUCH/CS0: B15.INT, B16.INT, R8.2; also elsewhere on the board
HAUPTPROGRAMM_D24: B1.INT, B2.INT, R1.1; also elsewhere on the board
HAUPTPROGRAMM_D25: B5.INT, B6.INT, R3.1; also elsewhere on the board
HAUPTPROGRAMM_D28: B9.INT, B10.INT, R5.1; also elsewhere on the board
HAUPTPROGRAMM_D40: B13.INT, B14.INT, R7.1; also elsewhere on the board
HAUPTPROGRAMM_D41: B17.INT, B18.INT, R9.1; also elsewhere on the board
HAUPTPROGRAMM_D42: B21.INT, B22.INT, R11.1; also elsewhere on the board
HAUPTPROGRAMM_D43/CS2: B25.INT, B26.INT, R13.1; also elsewhere on the board
HAUPTPROGRAMM_D44/MOSI2: B23.INT, B24.INT, R12.2; also elsewhere on the board
HAUPTPROGRAMM_D45/MISO2: B27.INT, B28.INT, R14.2; also elsewhere on the board
HAUPTPROGRAMM_D46/SCK2: B29.INT, B30.INT, R15.1; also elsewhere on the board
HAUPTPROGRAMM_D49/A23: B19.INT, B20.INT, R10.2; also elsewhere on the board
HAUPTPROGRAMM_D51/(MISO2): B31.INT, B32.INT, R16.2; also elsewhere on the board
HAUPTPROGRAMM_D53/(SCK2): B3.INT, B4.INT, R2.2; also elsewhere on the board
HAUPTPROGRAMM_D54/CS2: B7.INT, B8.INT, R4.2; also elsewhere on the board
HAUPTPROGRAMM_D55: B11.INT, B12.INT, R6.2; also elsewhere on the board
SENSORIK_D3/SCL2/CAN0TX/PWM: B1.SCL, B5.SCL, B9.SCL, B13.SCL, B17.SCL, B21.SCL, B25.SCL, B29.SCL, R18.2; also elsewhere on the board
SENSORIK_D4/SDA2/CAN0RX/PWM: B1.SDA, B5.SDA, B9.SDA, B13.SDA, B17.SDA, B21.SDA, B25.SDA, B29.SDA, R17.2; also elsewhere on the board
SENSORIK_D18/A4/TOUCH/SDA0: B2.SDA, B6.SDA, B10.SDA, B14.SDA, B18.SDA, B22.SDA, B26.SDA, B30.SDA, R19.2; also elsewhere on the board
SENSORIK_D19/A5/TOUCH/SCL0: B2.SCL, B6.SCL, B10.SCL, B14.SCL, B18.SCL, B22.SCL, B26.SCL, B30.SCL, R20.2; also elsewhere on the board
SENSORIK_D24: B29.ADDR, B30.ADDR, B31.ADDR, B32.ADDR; also elsewhere on the board
SENSORIK_D25: B25.ADDR, B26.ADDR, B27.ADDR, B28.ADDR; also elsewhere on the board
SENSORIK_D28: B21.ADDR, B22.ADDR, B23.ADDR, B24.ADDR; also elsewhere on the board
SENSORIK_D37/A18/SCL1/PWM: B3.SCL, B7.SCL, B11.SCL, B15.SCL, B19.SCL, B23.SCL, B27.SCL, B31.SCL, R22.2; also elsewhere on the board
SENSORIK_D38/A19/SDA1/PWM: B3.SDA, B7.SDA, B11.SDA, B15.SDA, B19.SDA, B23.SDA, B27.SDA, B31.SDA, R21.2; also elsewhere on the board
SENSORIK_D40: B17.ADDR, B18.ADDR, B19.ADDR, B20.ADDR; also elsewhere on the board
SENSORIK_D41: B13.ADDR, B14.ADDR, B15.ADDR, B16.ADDR; also elsewhere on the board
SENSORIK_D42: B9.ADDR, B10.ADDR, B11.ADDR, B12.ADDR; also elsewhere on the board
SENSORIK_D43/CS2: B5.ADDR, B6.ADDR, B7.ADDR, B8.ADDR; also elsewhere on the board
SENSORIK_D46/SCK2: B1.ADDR, B2.ADDR, B3.ADDR, B4.ADDR; also elsewhere on the board
SENSORIK_D56/SDA3: B4.SDA, B8.SDA, B12.SDA, B16.SDA, B20.SDA, B24.SDA, B28.SDA, B32.SDA, R23.2; also elsewhere on the board
SENSORIK_D57/SCL3: B4.SCL, B8.SCL, B12.SCL, B16.SCL, B20.SCL, B24.SCL, B28.SCL, B32.SCL, R24.2; also elsewhere on the board

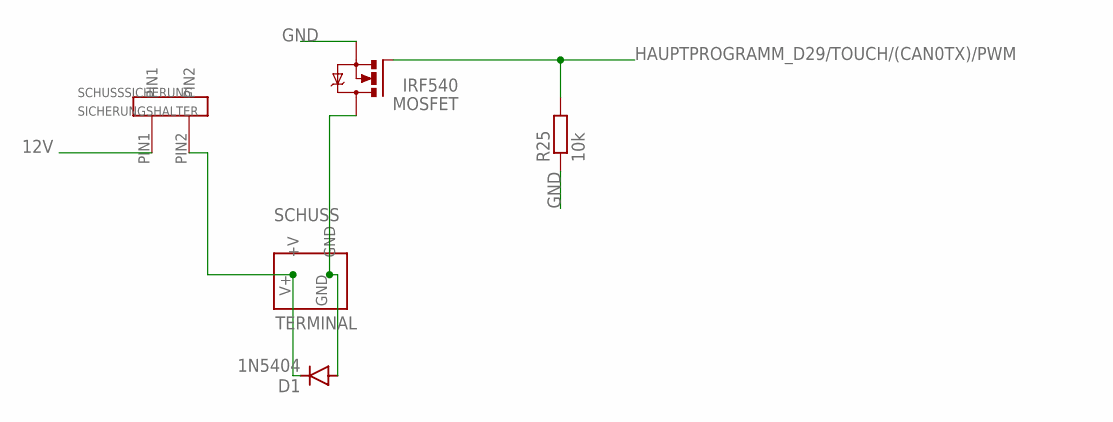
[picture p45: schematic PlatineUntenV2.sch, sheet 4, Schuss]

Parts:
D1: 1N5404; DO201-15
MOSFET: IRF540; TO220BV
R25: 10k; R0805
SCHUSS: TERMINAL
SCHUSSSICHERUNG: SICHERUNGSHALTER

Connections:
12V: SCHUSSSICHERUNG.PIN1; also elsewhere on the board
GND: MOSFET.S, R25.1; also elsewhere on the board
HAUPTPROGRAMM_D29/TOUCH/(CAN0TX)/PWM: MOSFET.G, R25.2; also elsewhere on the board
unnamed: D1.A, MOSFET.D, SCHUSS.GND
unnamed: D1.C, SCHUSS.V+ (+V), SCHUSSSICHERUNG.PIN2

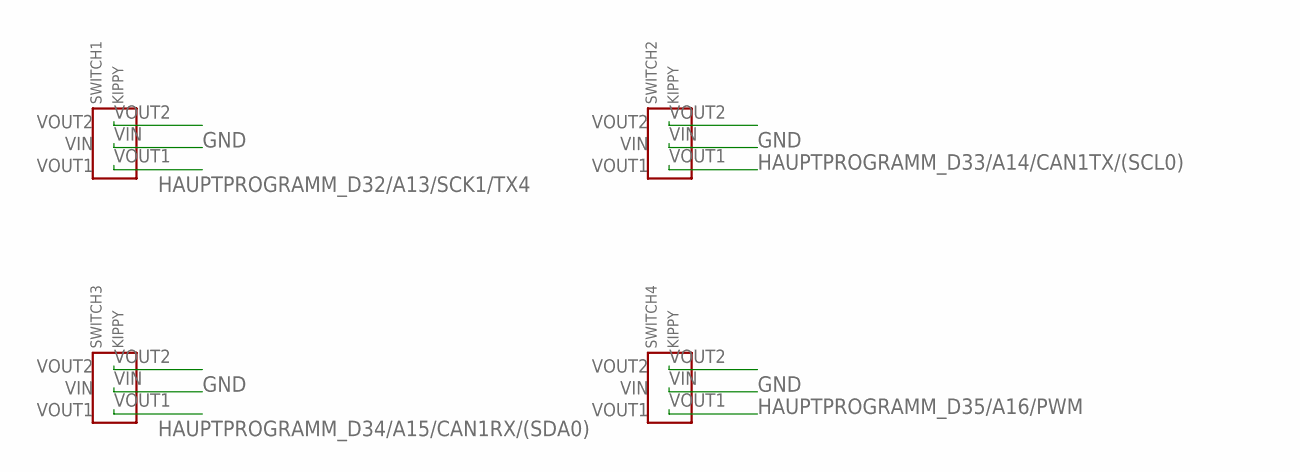
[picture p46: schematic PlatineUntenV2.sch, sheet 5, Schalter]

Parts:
SWITCH1, SWITCH2, SWITCH3, SWITCH4: KIPPY

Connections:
GND: SWITCH1.VIN, SWITCH2.VIN, SWITCH3.VIN, SWITCH4.VIN; also elsewhere on the board
HAUPTPROGRAMM_D32/A13/SCK1/TX4: SWITCH1.VOUT1; also elsewhere on the board
HAUPTPROGRAMM_D33/A14/CAN1TX/(SCL0): SWITCH2.VOUT1; also elsewhere on the board
HAUPTPROGRAMM_D34/A15/CAN1RX/(SDA0): SWITCH3.VOUT1; also elsewhere on the board
HAUPTPROGRAMM_D35/A16/PWM: SWITCH4.VOUT1; also elsewhere on the board

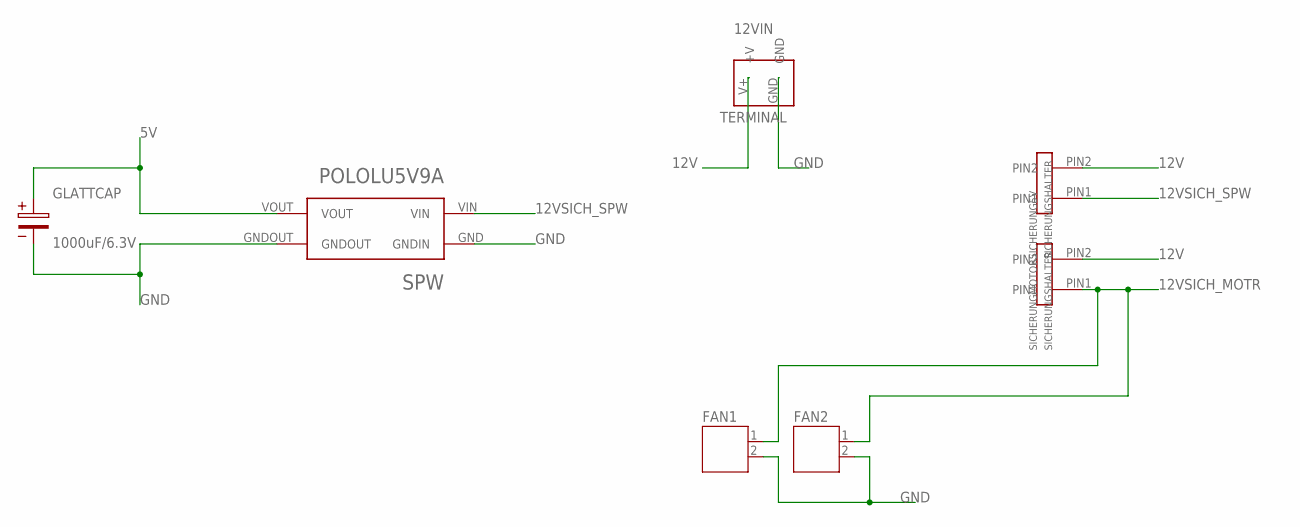
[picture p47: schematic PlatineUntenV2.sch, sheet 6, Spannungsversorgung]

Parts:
12VIN: TERMINAL
FAN1, FAN2: JST-PH2
GLATTCAP: 1000uF/6.3V; GLATTCAP
SICHERUNG5V: SICHERUNGSHALTER
SICHERUNGMOTOR: SICHERUNGSHALTER
SPW: POLOLU5V9A

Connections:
5V: GLATTCAP.1, SPW.VOUT; also elsewhere on the board
12V: 12VIN.V+ (+V), SICHERUNG5V.PIN2, SICHERUNGMOTOR.PIN2; also elsewhere on the board
12VSICH_MOTR: FAN1.1, FAN2.1, SICHERUNGMOTOR.PIN1; also elsewhere on the board
12VSICH_SPW: SICHERUNG5V.PIN1, SPW.VIN
GND: 12VIN.GND, FAN1.2, FAN2.2, GLATTCAP.2, SPW.GND (GNDIN), SPW.GNDOUT; also elsewhere on the board


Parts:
MOTOREN1/2, MOTOREN3/4: MOTORTREIBER

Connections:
3.3V: MOTOREN1/2.VDD(5V), MOTOREN3/4.VDD(5V); also elsewhere on the board
12VSICH_MOTR: MOTOREN1/2.VIN, MOTOREN3/4.VIN; also elsewhere on the board
GND: MOTOREN1/2.GND, MOTOREN1/2.GND(5V), MOTOREN3/4.GND, MOTOREN3/4.GND(5V); also elsewhere on the board
HAUPTPROGRAMM_D2/PWM: MOTOREN1/2.M1PWM2; also elsewhere on the board
HAUPTPROGRAMM_D4/SDA2/CAN0RX/PWM: MOTOREN1/2.M1SF; also elsewhere on the board
HAUPTPROGRAMM_D6/PWM: MOTOREN1/2.M2PWM2; also elsewhere on the board
HAUPTPROGRAMM_D7/(SCL0)/(MOSI0)/RX3/PWM: MOTOREN1/2.M2SF; also elsewhere on the board
HAUPTPROGRAMM_D11/MOSI0: MOTOREN3/4.M1SF; also elsewhere on the board
HAUPTPROGRAMM_D13/LED/SCK0: MOTOREN3/4.M2SF; also elsewhere on the board
HAUPTPROGRAMM_D14/A0/(SCK0)/PWM: MOTOREN3/4.M1PWM2; also elsewhere on the board
HAUPTPROGRAMM_D16/A2/TOUCH/(SCL0): MOTOREN1/2.M1IN1; also elsewhere on the board
HAUPTPROGRAMM_D17/A3/TOUCH/(SDA0): MOTOREN1/2.M1IN2; also elsewhere on the board
HAUPTPROGRAMM_D18/A4/TOUCH/SDA0: MOTOREN1/2.M2IN1; also elsewhere on the board
HAUPTPROGRAMM_D19/A5/TOUCH/SCL0: MOTOREN1/2.M2IN2; also elsewhere on the board
HAUPTPROGRAMM_D20/A6/CS0/(SCK1)/PWM: MOTOREN3/4.M2PWM2; also elsewhere on the board
HAUPTPROGRAMM_D21/A7/CS0/(MOSI1)/PWM: MOTOREN3/4.M1IN1; also elsewhere on the board
HAUPTPROGRAMM_D22/A8/TOUCH/PWM: MOTOREN3/4.M1IN2; also elsewhere on the board
HAUPTPROGRAMM_D23/A9/TOUCH/PWM: MOTOREN3/4.M2IN1; also elsewhere on the board
HAUPTPROGRAMM_D26/(TX1): MOTOREN3/4.M2IN2; also elsewhere on the board
HAUPTPROGRAMM_D36/A17/PWM: MOTOREN1/2.M1FB; also elsewhere on the board
HAUPTPROGRAMM_D37/A18/SCL1/PWM: MOTOREN1/2.M2FB; also elsewhere on the board
HAUPTPROGRAMM_D38/A19/SDA1/PWM: MOTOREN3/4.M1FB; also elsewhere on the board
HAUPTPROGRAMM_D39/A20: MOTOREN3/4.M2FB; also elsewhere on the board



Board: 4 copper layers, 200.0 x 186.9 mm, 152 parts (131 on the bottom side), 113 nets.

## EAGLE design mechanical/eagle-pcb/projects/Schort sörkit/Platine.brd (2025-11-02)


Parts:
ARDUINOKABEL1, ARDUINOKABEL2: T821140A1S100CEU_T821140A1S100CEU; T821140A1S100CEU_SHDR40W64P254X254_2X20_5842X89
M1: ARDUINO-NANO-3.0

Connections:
0: ARDUINOKABEL1.8
1: ARDUINOKABEL1.10
2: ARDUINOKABEL1.12; also elsewhere on the board
3: ARDUINOKABEL1.14; also elsewhere on the board
3.3VA: ARDUINOKABEL1.9
4: ARDUINOKABEL1.16; also elsewhere on the board
5: ARDUINOKABEL1.18; also elsewhere on the board
5V@0: ARDUINOKABEL1.3; also elsewhere on the board
5V@1: ARDUINOKABEL1.5
5V@2: ARDUINOKABEL1.7; also elsewhere on the board
6: ARDUINOKABEL1.20; also elsewhere on the board
7: ARDUINOKABEL1.22; also elsewhere on the board
8: ARDUINOKABEL1.24; also elsewhere on the board
9: ARDUINOKABEL1.26
10: ARDUINOKABEL1.28; also elsewhere on the board
11: ARDUINOKABEL1.30; also elsewhere on the board
12: ARDUINOKABEL1.32; also elsewhere on the board
12VAKKU: ARDUINOKABEL1.1, M1.J2.1 (VIN); also elsewhere on the board
13: ARDUINOKABEL2.3; also elsewhere on the board
14: ARDUINOKABEL2.5
15: ARDUINOKABEL2.7
16: ARDUINOKABEL2.9, M1.J1.2 (D0/RX)
17: ARDUINOKABEL2.11, M1.J1.1 (D1/TX)
18: ARDUINOKABEL2.13; also elsewhere on the board
19: ARDUINOKABEL2.15; also elsewhere on the board
20: ARDUINOKABEL2.17
21: ARDUINOKABEL2.19
22: ARDUINOKABEL2.21
23: ARDUINOKABEL2.23
24: ARDUINOKABEL2.25
25: ARDUINOKABEL2.27
26: ARDUINOKABEL2.29
27: ARDUINOKABEL2.31
28: ARDUINOKABEL2.33; also elsewhere on the board
29: ARDUINOKABEL2.35; also elsewhere on the board
30: ARDUINOKABEL2.37; also elsewhere on the board
31: ARDUINOKABEL2.39; also elsewhere on the board
32: ARDUINOKABEL2.2; also elsewhere on the board
33: ARDUINOKABEL2.4; also elsewhere on the board
34: ARDUINOKABEL2.6; also elsewhere on the board
35: ARDUINOKABEL2.8; also elsewhere on the board
36: ARDUINOKABEL2.10; also elsewhere on the board
37: ARDUINOKABEL2.12; also elsewhere on the board
38: ARDUINOKABEL2.14; also elsewhere on the board
39: ARDUINOKABEL2.16; also elsewhere on the board
40: ARDUINOKABEL2.18; also elsewhere on the board
41: ARDUINOKABEL2.20; also elsewhere on the board
42: ARDUINOKABEL2.22; also elsewhere on the board
43: ARDUINOKABEL2.24; also elsewhere on the board
44: ARDUINOKABEL2.26; also elsewhere on the board
45: ARDUINOKABEL2.28; also elsewhere on the board
46: ARDUINOKABEL2.30; also elsewhere on the board
47: ARDUINOKABEL2.32; also elsewhere on the board
48: ARDUINOKABEL2.34
49: ARDUINOKABEL2.36
50: ARDUINOKABEL2.38
51: ARDUINOKABEL2.40
A0: ARDUINOKABEL1.15
A1: ARDUINOKABEL1.17
A2: ARDUINOKABEL1.19
A3: ARDUINOKABEL1.21
A4: ARDUINOKABEL1.23
A5: ARDUINOKABEL1.25
A6: ARDUINOKABEL1.27
A7: ARDUINOKABEL1.29
A8: ARDUINOKABEL1.31
A9: ARDUINOKABEL1.33
A10: ARDUINOKABEL1.35
A11: ARDUINOKABEL1.37
A12: ARDUINOKABEL1.39
A13: ARDUINOKABEL1.2
A14: ARDUINOKABEL1.4
A15: ARDUINOKABEL1.6
AREFA: ARDUINOKABEL1.11
GND@0: ARDUINOKABEL1.34; also elsewhere on the board
GND@1: ARDUINOKABEL1.36
GND@2: ARDUINOKABEL1.38; also elsewhere on the board
GND@3: ARDUINOKABEL1.40
GNDAKKU: ARDUINOKABEL2.1, M1.J2.2 (GND.2); also elsewhere on the board
N2: M1.J1.5 (D2); also elsewhere on the board
N3: M1.J1.6 (D3); also elsewhere on the board
N3,3V: M1.J2.14 (3V3)
N4: M1.J1.7 (D4); also elsewhere on the board
N5: M1.J1.8 (D5); also elsewhere on the board
N5V: M1.J2.4 (5V)
N6: M1.J1.9 (D6); also elsewhere on the board
N7: M1.J1.10 (D7); also elsewhere on the board
N8: M1.J1.11 (D8); also elsewhere on the board
N9: M1.J1.12 (D9); also elsewhere on the board
N10: M1.J1.13 (D10); also elsewhere on the board
N11: M1.J1.14 (D11/MOSI); also elsewhere on the board
N12: M1.J1.15 (D12/MISO); also elsewhere on the board
N13: M1.J2.15 (D13/SCK)
NA0: M1.J2.12 (A0)
NA1: M1.J2.11 (A1)
NA2: M1.J2.10 (A2)
NA3: M1.J2.9 (A3)
NA4: M1.J2.8 (A4)
NA5: M1.J2.7 (A5)
NA6: M1.J2.6 (A6)
NA7: M1.J2.5 (A7)
NAREF: M1.J2.13 (AREF)
NGND@1: M1.J1.4 (GND.1)
NRESET: M1.J1.3 (RST.1)
RESETA: ARDUINOKABEL1.13


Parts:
U$1, U$2, U$3, U$4: ULTRASONIC-HC-SR04#V

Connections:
2: U$3.3 (ECHO); also elsewhere on the board
3: U$4.3 (ECHO); also elsewhere on the board
4: U$4.2 (TRIG); also elsewhere on the board
5: U$3.2 (TRIG); also elsewhere on the board
5V@0: U$1.1 (VCC), U$2.1 (VCC), U$3.1 (VCC), U$4.1 (VCC); also elsewhere on the board
6: U$1.2 (TRIG); also elsewhere on the board
8: U$2.2 (TRIG); also elsewhere on the board
18: U$1.3 (ECHO); also elsewhere on the board
19: U$2.3 (ECHO); also elsewhere on the board
GND@0: U$1.4 (GND), U$2.4 (GND), U$3.4 (GND), U$4.4 (GND); also elsewhere on the board


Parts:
F1, F2, F3, F4, F5, F6, F7, F8: FOTOWIDERSTAND
R65, R66, R67, R68, R69, R70, R71, R72: 470K; 0207/7
U$6: MCP3008P; DIL16

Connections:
5V@0: F1.P2, F2.P2, F3.P2, F4.P2, F5.P2, F6.P2, F7.P2, F8.P2, U$6.15 (VREF), U$6.16 (VDD); also elsewhere on the board
CH0: F8.P1, R72.2, U$6.1 (CH0)
CH1: F7.P1, R71.2, U$6.2 (CH1)
CH2: F6.P1, R70.2, U$6.3 (CH2)
CH3: F5.P1, R69.2, U$6.4 (CH3)
CH4: F4.P1, R68.2, U$6.5 (CH4)
CH5: F3.P1, R67.2, U$6.6 (CH5)
CH6: F2.P1, R66.2, U$6.7 (CH6)
CH7: F1.P1, R65.2, U$6.8 (CH7)
GND@0: R65.1, R66.1, R67.1, R68.1, R69.1, R70.1, R71.1, R72.1, U$6.9 (GND), U$6.14 (AGND); also elsewhere on the board
N2: U$6.13 (SCK); also elsewhere on the board
N3: U$6.12 (MISO); also elsewhere on the board
N4: U$6.11 (MOSI); also elsewhere on the board
N5: U$6.10 (!CS); also elsewhere on the board


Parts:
F9, F10, F11, F12, F13, F14, F15, F16: FOTOWIDERSTAND
R73, R74, R75, R76, R77, R78, R79, R80: 470K; 0207/7
U$7: MCP3008P; DIL16

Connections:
5V@0: F9.P2, F10.P2, F11.P2, F12.P2, F13.P2, F14.P2, F15.P2, F16.P2, U$7.15 (VREF), U$7.16 (VDD); also elsewhere on the board
CH8: F16.P1, R80.2, U$7.1 (CH0)
CH9: F15.P1, R79.2, U$7.2 (CH1)
CH10: F14.P1, R78.2, U$7.3 (CH2)
CH11: F13.P1, R77.2, U$7.4 (CH3)
CH12: F12.P1, R76.2, U$7.5 (CH4)
CH13: F11.P1, R75.2, U$7.6 (CH5)
CH14: F10.P1, R74.2, U$7.7 (CH6)
CH15: F9.P1, R73.2, U$7.8 (CH7)
GND@0: R73.1, R74.1, R75.1, R76.1, R77.1, R78.1, R79.1, R80.1, U$7.9 (GND), U$7.14 (AGND); also elsewhere on the board
N2: U$7.13 (SCK); also elsewhere on the board
N3: U$7.12 (MISO); also elsewhere on the board
N4: U$7.11 (MOSI); also elsewhere on the board
N6: U$7.10 (!CS); also elsewhere on the board


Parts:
F17, F18, F19, F20, F21, F22, F23, F24: FOTOWIDERSTAND
R81, R82, R83, R84, R85, R86, R87, R88: 470K; 0207/7
U$8: MCP3008P; DIL16

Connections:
5V@0: F17.P2, F18.P2, F19.P2, F20.P2, F21.P2, F22.P2, F23.P2, F24.P2, U$8.15 (VREF), U$8.16 (VDD); also elsewhere on the board
CH16: F24.P1, R88.2, U$8.1 (CH0)
CH17: F23.P1, R87.2, U$8.2 (CH1)
CH18: F22.P1, R86.2, U$8.3 (CH2)
CH19: F21.P1, R85.2, U$8.4 (CH3)
CH20: F20.P1, R84.2, U$8.5 (CH4)
CH21: F19.P1, R83.2, U$8.6 (CH5)
CH22: F18.P1, R82.2, U$8.7 (CH6)
CH23: F17.P1, R81.2, U$8.8 (CH7)
GND@0: R81.1, R82.1, R83.1, R84.1, R85.1, R86.1, R87.1, R88.1, U$8.9 (GND), U$8.14 (AGND); also elsewhere on the board
N2: U$8.13 (SCK); also elsewhere on the board
N3: U$8.12 (MISO); also elsewhere on the board
N4: U$8.11 (MOSI); also elsewhere on the board
N7: U$8.10 (!CS); also elsewhere on the board

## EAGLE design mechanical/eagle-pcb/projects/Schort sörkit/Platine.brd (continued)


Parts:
F25, F26, F27, F28, F29, F30, F31, F32: FOTOWIDERSTAND
R89, R90, R91, R92, R93, R94, R95, R96: 470K; 0207/7
U$10: MCP3008P; DIL16

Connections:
5V@0: F25.P2, F26.P2, F27.P2, F28.P2, F29.P2, F30.P2, F31.P2, F32.P2, U$10.15 (VREF), U$10.16 (VDD); also elsewhere on the board
CH24: F32.P1, R96.2, U$10.1 (CH0)
CH25: F31.P1, R95.2, U$10.2 (CH1)
CH26: F30.P1, R94.2, U$10.3 (CH2)
CH27: F29.P1, R93.2, U$10.4 (CH3)
CH28: F28.P1, R92.2, U$10.5 (CH4)
CH29: F27.P1, R91.2, U$10.6 (CH5)
CH30: F26.P1, R90.2, U$10.7 (CH6)
CH31: F25.P1, R89.2, U$10.8 (CH7)
GND@0: R89.1, R90.1, R91.1, R92.1, R93.1, R94.1, R95.1, R96.1, U$10.9 (GND), U$10.14 (AGND); also elsewhere on the board
N2: U$10.13 (SCK); also elsewhere on the board
N3: U$10.12 (MISO); also elsewhere on the board
N4: U$10.11 (MOSI); also elsewhere on the board
N8: U$10.10 (!CS); also elsewhere on the board


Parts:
F33, F34, F35, F36, F37, F38, F39, F40: FOTOWIDERSTAND
R97, R98, R99, R100, R101, R102, R103, R104: 470K; 0207/7
U$11: MCP3008P; DIL16

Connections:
5V@0: F33.P2, F34.P2, F35.P2, F36.P2, F37.P2, F38.P2, F39.P2, F40.P2, U$11.15 (VREF), U$11.16 (VDD); also elsewhere on the board
CH32: F40.P1, R104.2, U$11.1 (CH0)
CH33: F39.P1, R103.2, U$11.2 (CH1)
CH34: F38.P1, R102.2, U$11.3 (CH2)
CH35: F37.P1, R101.2, U$11.4 (CH3)
CH36: F36.P1, R100.2, U$11.5 (CH4)
CH37: F35.P1, R99.2, U$11.6 (CH5)
CH38: F34.P1, R98.2, U$11.7 (CH6)
CH39: F33.P1, R97.2, U$11.8 (CH7)
GND@0: R97.1, R98.1, R99.1, R100.1, R101.1, R102.1, R103.1, R104.1, U$11.9 (GND), U$11.14 (AGND); also elsewhere on the board
N2: U$11.13 (SCK); also elsewhere on the board
N3: U$11.12 (MISO); also elsewhere on the board
N4: U$11.11 (MOSI); also elsewhere on the board
N9: U$11.10 (!CS); also elsewhere on the board


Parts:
F41, F42, F43, F44, F45, F46, F47, F48: FOTOWIDERSTAND
R105, R106, R107, R108, R109, R110, R111, R112: 470K; 0207/7
U$12: MCP3008P; DIL16

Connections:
5V@0: F41.P2, F42.P2, F43.P2, F44.P2, F45.P2, F46.P2, F47.P2, F48.P2, U$12.15 (VREF), U$12.16 (VDD); also elsewhere on the board
CH40: F48.P1, R112.2, U$12.1 (CH0)
CH41: F47.P1, R111.2, U$12.2 (CH1)
CH42: F46.P1, R110.2, U$12.3 (CH2)
CH43: F45.P1, R109.2, U$12.4 (CH3)
CH44: F44.P1, R108.2, U$12.5 (CH4)
CH45: F43.P1, R107.2, U$12.6 (CH5)
CH46: F42.P1, R106.2, U$12.7 (CH6)
CH47: F41.P1, R105.2, U$12.8 (CH7)
GND@0: R105.1, R106.1, R107.1, R108.1, R109.1, R110.1, R111.1, R112.1, U$12.9 (GND), U$12.14 (AGND); also elsewhere on the board
N2: U$12.13 (SCK); also elsewhere on the board
N3: U$12.12 (MISO); also elsewhere on the board
N4: U$12.11 (MOSI); also elsewhere on the board
N10: U$12.10 (!CS); also elsewhere on the board

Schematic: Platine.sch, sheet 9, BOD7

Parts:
F49, F50, F51, F52, F53, F54, F55, F56: FOTOWIDERSTAND
R113, R114, R115, R116, R117, R118, R119, R120: 470K; 0207/7
U$13: MCP3008P; DIL16

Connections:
5V@0: F49.P2, F50.P2, F51.P2, F52.P2, F53.P2, F54.P2, F55.P2, F56.P2, U$13.15 (VREF), U$13.16 (VDD); also elsewhere on the board
CH48: F56.P1, R120.2, U$13.1 (CH0)
CH49: F55.P1, R119.2, U$13.2 (CH1)
CH50: F54.P1, R118.2, U$13.3 (CH2)
CH51: F53.P1, R117.2, U$13.4 (CH3)
CH52: F52.P1, R116.2, U$13.5 (CH4)
CH53: F51.P1, R115.2, U$13.6 (CH5)
CH54: F50.P1, R114.2, U$13.7 (CH6)
CH55: F49.P1, R113.2, U$13.8 (CH7)
GND@0: R113.1, R114.1, R115.1, R116.1, R117.1, R118.1, R119.1, R120.1, U$13.9 (GND), U$13.14 (AGND); also elsewhere on the board
N2: U$13.13 (SCK); also elsewhere on the board
N3: U$13.12 (MISO); also elsewhere on the board
N4: U$13.11 (MOSI); also elsewhere on the board
N11: U$13.10 (!CS); also elsewhere on the board

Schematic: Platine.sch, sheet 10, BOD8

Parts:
F57, F58, F59, F60, F61, F62, F63, F64: FOTOWIDERSTAND
R121, R122, R123, R124, R125, R126, R127, R128: 470K; 0207/7
U$14: MCP3008P; DIL16

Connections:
5V@0: F57.P2, F58.P2, F59.P2, F60.P2, F61.P2, F62.P2, F63.P2, F64.P2, U$14.15 (VREF), U$14.16 (VDD); also elsewhere on the board
CH56: F64.P1, R128.2, U$14.1 (CH0)
CH57: F63.P1, R127.2, U$14.2 (CH1)
CH58: F62.P1, R126.2, U$14.3 (CH2)
CH59: F61.P1, R125.2, U$14.4 (CH3)
CH60: F60.P1, R124.2, U$14.5 (CH4)
CH61: F59.P1, R123.2, U$14.6 (CH5)
CH62: F58.P1, R122.2, U$14.7 (CH6)
CH63: F57.P1, R121.2, U$14.8 (CH7)
GND@0: R121.1, R122.1, R123.1, R124.1, R125.1, R126.1, R127.1, R128.1, U$14.9 (GND), U$14.14 (AGND); also elsewhere on the board
N2: U$14.13 (SCK); also elsewhere on the board
N3: U$14.12 (MISO); also elsewhere on the board
N4: U$14.11 (MOSI); also elsewhere on the board
N12: U$14.10 (!CS); also elsewhere on the board

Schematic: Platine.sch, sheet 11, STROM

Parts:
AKKU: TERMINAL
SH1, SH2, SH3, SH4: SHORT-HA5; SHORT_ALL-50
SPANNUNGSWANDLERAUSGANG: TERMINAL

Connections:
5VSPW: SPANNUNGSWANDLERAUSGANG.V+ (+V); also elsewhere on the board
12VAKKU: AKKU.V+ (+V), SH3.2, SH4.2; also elsewhere on the board
12VMOTOR: SH4.1; also elsewhere on the board
12VSCHUSS: SH3.1; also elsewhere on the board
GNDAKKU: AKKU.GND, SH1.1, SH2.1; also elsewhere on the board
GNDMOTOR: SH1.2; also elsewhere on the board
GNDSCHUSS: SH2.2; also elsewhere on the board
GNDSPW: SPANNUNGSWANDLERAUSGANG.GND; also elsewhere on the board

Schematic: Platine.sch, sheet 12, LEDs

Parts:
LED1, LED2, LED3, LED4, LED5, LED6, LED7, LED8, LED9, LED10, LED11, LED12, LED13, LED14, LED15, LED16, LED17, LED18, LED19, LED20, LED21, LED22, LED23, LED24, LED25, LED26, LED27, LED28, LED29, LED30, LED31, LED32, LED33, LED34, LED35, LED36, LED37, LED38, LED39, LED40, LED41, LED42, LED43, LED44, LED45, LED46, LED47, LED48, LED49, LED50, LED51, LED52, LED53, LED54, LED55, LED56, LED57, LED58, LED59, LED60, LED61, LED62, LED63, LED64: LEDLED3MM2; 3MM
RL1, RL2, RL3, RL4, RL5, RL6, RL7, RL8, RL9, RL10, RL11, RL12, RL13, RL14, RL15, RL16, RL17, RL18, RL19, RL20, RL21, RL22, RL23, RL24, RL25, RL26, RL27, RL28, RL29, RL30, RL31, RL32, RL33, RL34, RL35, RL36, RL37, RL38, RL39, RL40, RL41, RL42, RL43, RL44, RL45, RL46, RL47, RL48, RL49, RL50, RL51, RL52, RL53, RL54, RL55, RL56, RL57, RL58, RL59, RL60, RL61, RL62, RL63, RL64: 130; 0207/7

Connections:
5VSPW: RL1.1, RL2.1, RL3.1, RL4.1, RL5.1, RL6.1, RL7.1, RL8.1, RL9.1, RL10.1, RL11.1, RL12.1, RL13.1, RL14.1, RL15.1, RL16.1, RL17.1, RL18.1, RL19.1, RL20.1, RL21.1, RL22.1, RL23.1, RL24.1, RL25.1, RL26.1, RL27.1, RL28.1, RL29.1, RL30.1, RL31.1, RL32.1, RL33.1, RL34.1, RL35.1, RL36.1, RL37.1, RL38.1, RL39.1, RL40.1, RL41.1, RL42.1, RL43.1, RL44.1, RL45.1, RL46.1, RL47.1, RL48.1, RL49.1, RL50.1, RL51.1, RL52.1, RL53.1, RL54.1, RL55.1, RL56.1, RL57.1, RL58.1, RL59.1, RL60.1, RL61.1, RL62.1, RL63.1, RL64.1; also elsewhere on the board
GNDSPW: LED1.K (C), LED2.K (C), LED3.K (C), LED4.K (C), LED5.K (C), LED6.K (C), LED7.K (C), LED8.K (C), LED9.K (C), LED10.K (C), LED11.K (C), LED12.K (C), LED13.K (C), LED14.K (C), LED15.K (C), LED16.K (C), LED17.K (C), LED18.K (C), LED19.K (C), LED20.K (C), LED21.K (C), LED22.K (C), LED23.K (C), LED24.K (C), LED25.K (C), LED26.K (C), LED27.K (C), LED28.K (C), LED29.K (C), LED30.K (C), LED31.K (C), LED32.K (C), LED33.K (C), LED34.K (C), LED35.K (C), LED36.K (C), LED37.K (C), LED38.K (C), LED39.K (C), LED40.K (C), LED41.K (C), LED42.K (C), LED43.K (C), LED44.K (C), LED45.K (C), LED46.K (C), LED47.K (C), LED48.K (C), LED49.K (C), LED50.K (C), LED51.K (C), LED52.K (C), LED53.K (C), LED54.K (C), LED55.K (C), LED56.K (C), LED57.K (C), LED58.K (C), LED59.K (C), LED60.K (C), LED61.K (C), LED62.K (C), LED63.K (C), LED64.K (C); also elsewhere on the board
unnamed: LED4.A, RL4.2
unnamed: LED3.A, RL3.2
unnamed: LED2.A, RL2.2
unnamed: LED1.A, RL1.2
unnamed: LED8.A, RL8.2
unnamed: LED7.A, RL7.2
unnamed: LED6.A, RL6.2
unnamed: LED5.A, RL5.2
unnamed: LED12.A, RL12.2
unnamed: LED11.A, RL11.2
unnamed: LED10.A, RL10.2
unnamed: LED9.A, RL9.2
unnamed: LED16.A, RL16.2
unnamed: LED15.A, RL15.2
unnamed: LED14.A, RL14.2
unnamed: LED13.A, RL13.2
unnamed: LED20.A, RL20.2
unnamed: LED19.A, RL19.2
unnamed: LED18.A, RL18.2
unnamed: LED17.A, RL17.2
unnamed: LED24.A, RL24.2
unnamed: LED23.A, RL23.2
unnamed: LED22.A, RL22.2
unnamed: LED21.A, RL21.2
unnamed: LED28.A, RL28.2
unnamed: LED27.A, RL27.2
unnamed: LED26.A, RL26.2
unnamed: LED25.A, RL25.2
unnamed: LED32.A, RL32.2
unnamed: LED31.A, RL31.2
unnamed: LED30.A, RL30.2
unnamed: LED29.A, RL29.2
unnamed: LED36.A, RL36.2
unnamed: LED35.A, RL35.2
unnamed: LED34.A, RL34.2
unnamed: LED33.A, RL33.2
unnamed: LED40.A, RL40.2
unnamed: LED39.A, RL39.2
unnamed: LED38.A, RL38.2
unnamed: LED37.A, RL37.2
unnamed: LED44.A, RL44.2
unnamed: LED43.A, RL43.2
unnamed: LED42.A, RL42.2
unnamed: LED41.A, RL41.2
unnamed: LED48.A, RL48.2
unnamed: LED47.A, RL47.2
unnamed: LED46.A, RL46.2
unnamed: LED45.A, RL45.2
unnamed: LED52.A, RL52.2
unnamed: LED51.A, RL51.2
unnamed: LED50.A, RL50.2
unnamed: LED49.A, RL49.2
unnamed: LED56.A, RL56.2
unnamed: LED55.A, RL55.2
unnamed: LED54.A, RL54.2
unnamed: LED53.A, RL53.2
unnamed: LED60.A, RL60.2
unnamed: LED59.A, RL59.2
unnamed: LED58.A, RL58.2
unnamed: LED57.A, RL57.2
unnamed: LED64.A, RL64.2
unnamed: LED63.A, RL63.2
unnamed: LED62.A, RL62.2
unnamed: LED61.A, RL61.2

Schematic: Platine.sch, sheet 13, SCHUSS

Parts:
10A: FUSESH35; SH25
D1: 1N5404; DO201-15
Q1: IRF540; TO220
SCHUSS: TERMINAL

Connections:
7: Q1.1 (G); also elsewhere on the board
12VSCHUSS: 10A.1; also elsewhere on the board
GNDSCHUSS: Q1.3 (S); also elsewhere on the board
unnamed: D1.A, Q1.2 (D), SCHUSS.GND
unnamed: 10A.2, D1.C, SCHUSS.V+ (+V)

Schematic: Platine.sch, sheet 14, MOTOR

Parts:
MOTOREN1-2, MOTOREN3-4: MOTORTREIBER

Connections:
5V@2: MOTOREN1-2.VDD(5V), MOTOREN3-4.VDD(5V); also elsewhere on the board
12VMOTOR: MOTOREN1-2.VIN, MOTOREN3-4.VIN; also elsewhere on the board
28: MOTOREN1-2.M1FB; also elsewhere on the board
29: MOTOREN1-2.M1SF; also elsewhere on the board
30: MOTOREN1-2.M2FB; also elsewhere on the board
31: MOTOREN1-2.M2SF; also elsewhere on the board
32: MOTOREN3-4.M1FB; also elsewhere on the board
33: MOTOREN3-4.M1SF; also elsewhere on the board
34: MOTOREN3-4.M2FB; also elsewhere on the board
35: MOTOREN3-4.M2SF; also elsewhere on the board
36: MOTOREN1-2.M1IN1; also elsewhere on the board
37: MOTOREN1-2.M1IN2; also elsewhere on the board
38: MOTOREN1-2.M2IN1; also elsewhere on the board
39: MOTOREN1-2.M2IN2; also elsewhere on the board
40: MOTOREN3-4.M1IN1; also elsewhere on the board
41: MOTOREN3-4.M1IN2; also elsewhere on the board
42: MOTOREN3-4.M2IN1; also elsewhere on the board
43: MOTOREN3-4.M2IN2; also elsewhere on the board
44: MOTOREN1-2.M1PWM2; also elsewhere on the board
45: MOTOREN1-2.M2PWM2; also elsewhere on the board
46: MOTOREN3-4.M1PWM2; also elsewhere on the board
47: MOTOREN3-4.M2PWM2; also elsewhere on the board
GND@2: MOTOREN1-2.GND(5V), MOTOREN3-4.GND(5V); also elsewhere on the board
GNDMOTOR: MOTOREN1-2.GND, MOTOREN3-4.GND; also elsewhere on the board

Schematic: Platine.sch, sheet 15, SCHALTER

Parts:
SWITCH1, SWITCH2, SWITCH3, SWITCH4: KIPPY

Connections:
10: SWITCH1.VOUT1; also elsewhere on the board
11: SWITCH2.VOUT1; also elsewhere on the board
12: SWITCH3.VOUT1; also elsewhere on the board
13: SWITCH4.VOUT1; also elsewhere on the board
GND@2: SWITCH1.VIN, SWITCH2.VIN, SWITCH3.VIN, SWITCH4.VIN; also elsewhere on the board

Board: 4 copper layers, 287 parts (128 on the bottom side), 188 nets, no tracks yet.

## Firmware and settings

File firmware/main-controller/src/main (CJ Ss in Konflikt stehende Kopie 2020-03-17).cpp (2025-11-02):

#include "Arduino.h"
#include "PIN_NAMES.h"
//#include "MotorSpeeds.h"
#include "Motors.h"

int angle;
Motors motors;
long start;
long delta;

void setup() {
        Serial.begin(9600);
        motors.initMotors();
}
void loop() {
        if (millis() > start + 1000) {
                start = millis();
                if (angle == 0) {
                        angle = 90;
                }
                else if (angle == 90) {
                        angle = 0;
                }
        }
        uint8_t length = Serial.available();
        if (length > 0) {
                //Serial.print("Received message of length: ");
                //Serial.println(length);
                for (uint8_t i = 0; i < length; i++) {
                        int newAngle = Serial.read();
                        if (newAngle == 'w') {
                                angle = 0;
                        }
                        else if (newAngle == 'a') {
                                angle = 90;
                        }
                        else if (newAngle == 's') {
                                angle = -180;
                        }
                        else if (newAngle == 'd') {
                                angle = -90;
                        }
                }
        }
        if (angle == 0) {
                //motors.stop();
        }
        else {
                //motors.setSpeeds(angle, 0);
        }
        if (motors.getFeedback(3) < 200) {
                motors.setDribblerSpeed(255);
        }
        else {
                motors.setDribblerSpeed(0);
        }
        motors.writeSpeeds();
        //Serial.println(ACTIVE_BRAKE * motors.getFeedback(2));
        Serial.println(motors.getFeedback(3));
}

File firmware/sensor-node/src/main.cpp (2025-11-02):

// Sensorik Hauptprogramm
#include <Arduino.h>
#include "TOF.h"
#include "IMU.h"
#include "COM.h"
#include "Bodensensoren.h"
#include "i2c_t3.h"
#include "PIN_NAMES.h"
#include "VL53L1X.h"

IMU IMU;
TOF TOF;
Bodensensoren BODEN;
Transmitter TRANSMIT;
uint16_t maxValues[32] = {0};
uint16_t minValues[32] = {10000};

void calibBoden() {
        for (int i = 0; i < 32; i++) {
                maxValues[i] = max(maxValues[i], BODEN.getBoden(i).getLuminosity(0));
                minValues[i] = min(minValues[i], BODEN.getBoden(i).getLuminosity(0));
                BODEN.calibValues[i] = minValues[i] + ((maxValues[i] - minValues[i]) / 2);
                Serial.println(BODEN.getBoden(i).getThreshold());
        }
        BODEN.setThresholds();
}

void setup() {
        delay(100);
        Serial.begin(9600);
        TRANSMIT.init();
        TOF.init();
        BODEN.initSecond();
        IMU.init();
        TRANSMIT.setCompass(362);
        TRANSMIT.transmit();
        TRANSMIT.setError(5);
        TRANSMIT.setTofRight(20);
        TRANSMIT.setTofFront(20);
        TRANSMIT.setTofLeft(20);
        TRANSMIT.setLine(20);
        delay(2);
        TOF.readRight();
        TOF.readFront();
        TOF.readLeft();
        TOF.readBack();
        delay(2);
}
void scan();
void loop() {
        int a = IMU.getAngle();
        int line = BODEN.resetInterrupt();
        TRANSMIT.setCompass(a);
        TRANSMIT.setError(5);
        TRANSMIT.setTofFront(TOF.readBack());
        TRANSMIT.setTofRight(TOF.readRight());
        TRANSMIT.setTofLeft(TOF.readLeft());
        if (TRANSMIT.getCurrentCommand() == 1) {
                calibBoden();
        }
        else if (TRANSMIT.getCurrentCommand() == 2) {
                IMU.setZero();
        }
        // else if (TRANSMIT.getCurrentCommand() == 3) {
        //         IMU.callibrate(5000);
        // }
        TRANSMIT.setLine(line);
        TRANSMIT.transmit();
        // Serial.println(a);
        Serial.println(millis());
}

void scan() {
        byte error, address;
        int nDevices;

        Serial.println("Scanning...");

        nDevices = 0;
        for(address = 1; address < 127; address++ )
        {
                // The i2c_scanner uses the return value of
                // the Write.endTransmisstion to see if
                // a device did acknowledge to the address.
                Wire.beginTransmission(address);
                error = Wire.endTransmission();

                Serial.print("Got Error: ");
                Serial.print(error);
                Serial.print(" at address 0x");
                if (address<16)
                        Serial.print("0");
                Serial.print(address,HEX);
                Serial.println("  !");

                if (error == 0)
                {
                        Serial.print("I2C device found at address 0x");
                        if (address<16)
                                Serial.print("0");
                        Serial.print(address,HEX);
                        Serial.println("  !");

                        nDevices++;
                }
                else if (error==4)
                {
                        Serial.print("Unknown error at address 0x");
                        if (address<16)
                                Serial.print("0");
                        Serial.println(address,HEX);
                }
        }
        if (nDevices == 0)
                Serial.println("No I2C devices found\n");
        else
                Serial.println("done\n");
}

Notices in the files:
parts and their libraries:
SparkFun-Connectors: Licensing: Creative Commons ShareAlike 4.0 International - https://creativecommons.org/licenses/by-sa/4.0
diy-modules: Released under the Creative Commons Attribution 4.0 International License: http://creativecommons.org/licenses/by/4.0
